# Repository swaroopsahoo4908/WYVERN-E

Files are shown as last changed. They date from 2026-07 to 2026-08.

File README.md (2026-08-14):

# GTR70E WYVERN

**Authors:** Swaroop Sahoo, Chris Liu, Allison Hong  
**Program:** GTR70E WYVERN

A single-stage, 70 mm, finned active-TVC sustainer built around a **Raspberry Pi Pico 2 W** on a
20 x 24 (50 x 70 mm) perfboard, mounted as an axial card in the avionics bay, powered by an
**Estes F15-4**.

The vehicle answers five research questions, run across computational simulation, ground-based
instrumented testing, and powered flight:

- **RQ1, actuator class.** Magnetic-solenoid vs. servo thrust-vector control, compared on two
  physically separate, instrumentally identical three-axis load balances. The vehicle flies servo.
- **RQ2, zoned materials.** ASA-Aero, PETG-CF, and PC-FR allocated by section (upper body, lower
  body/fins, TVC assembly), justified by bend-to-fracture and thermal data, plus a blast-shield
  materials screen on the static-fire stand.
- **RQ3, fin aerofoil selection.** Bench wind-tunnel measurement of candidate fin sections,
  cross-checked against a 2D vortex-panel CFD solver.
- **RQ4, wind-tunnel-vs-flight calibration.** Barrowman-predicted stability checked against both
  tunnel measurement and reconstructed flight telemetry.
- **RQ5, control-gain sensitivity.** Closed-loop PID gain sets compared across repeated flights on
  the single-controller avionics architecture.

## Vehicle summary

Single stage, one Pico 2 W as flight computer and real-time controller: dual-core RP2350, one core
dedicated to the 500 Hz TVC loop, no Linux, native hardware PWM. Telemetry is logged to microSD as
the data of record; the onboard CYW43439 radio is used for bench telemetry on the ground stand. The magnetic-vs-servo comparison
runs on the ground (two matched three-axis load balances) rather than in flight, since that gives a
repeatable, directly-measured thrust vector instead of a single noisy flight-to-flight data point.

**Materials.** ASA-Aero forms the upper body that houses avionics (nose, recovery bay tube, FC bay
tube) and the lower body tube (chute/TVC bay); PETG-CF forms the fins and the bulkhead joint; PC-FR
forms the TVC assembly proper (motor mount, gimbal). Zoning follows thermal exposure and structural
role, not a single blanket material.

## Key numbers (see `Simulations/we4_sim.py` → `plots4/`)

| | value |
|---|---|
| Liftoff / dry mass | **720 g / 660 g** (finned 87 mm, no ballast) |
| T/W | 2.04 avg / 3.58 peak |
| Overall length | **672 mm** (Upper BT 198.4 · bulkhead 4 · Lower BT 350 · nose 120) |
| CG / CP / margin | 45.0 cm / 53.3 cm / **+1.14 cal** |
| Gimbal pivot / control arm | 54.8 cm / 9.9 cm from nose |
| Pitch inertia Iyy | 0.0201 kg·m² |
| Pitch authority | 17.2 rad/s² at the ±8° limit |
| Burnout | 3.45 s · 70.1 m · 34.4 m/s |
| Apogee | ~409 ft / 124.6 m @ 6.72 s (RK4+Barrowman) |
| Recovery | F15-4 motor ejection; deploys t≈7.45 s (+0.71 s past apogee) @ ~7.1 m/s; 24″ chute → 4.8 m/s descent |
| TVC | gimbal stays within ±8°; control authority positive throughout the burn |
| FAA class | Class 1, no waiver (720 g < 1500 g, F-class motor) |
| Flight computer | Pico 2 W on a 20×24 (50×70 mm) perfboard, axial card in the Upper BT |
| Sensors | BNO085 ×2 (bay 0x4B, gimbal 0x4A) · BME688 0x76 · BMP388 0x77 · microSD on SPI1 |
| Power | 2S 450 mAh LiPo → PPTC → arming switch → 5 V 3 A switching UBEC |
| Launch window | Nov 7–8 2026 primary, Nov 14–15 contingency; data close-out Dec 1 |

## Repository structure

```
GTR70E WYVERN/
├── README.md ← this file
├── .gitignore
├── Documentation/ ← all engineering docs, BOM, and build readiness
│ ├── README.md ← documentation index
│ ├── WYVERN_E4_BUILD_READINESS.md ← GO/NO-GO reconciliation report
│ ├── WYVERN_E4_Mathematics.md ← mass/CG/inertia, T/W, trajectory, TVC, recovery
│ ├── WYVERN_E4_Stability_FinSizing.md
│ ├── WYVERN_E4_FEA_Structural.md
│ ├── WYVERN_E4_Recovery.md
│ ├── WYVERN_E4_Camera_Solution.md
│ ├── WYVERN_E4_GSE_TestStands.md
│ ├── WYVERN_E4_PID_AUTOTUNE_REPORT.md
│ ├── WYVERN_E4_BOM.xlsx ← master BOM + purchase links
│ ├── WYVERN_E4_Timeline_3Month.md ← build-to-flight schedule
│ ├── WYVERN_E4_Build_Guide.md ← print/bench/assembly/ground-test/range procedures
│ ├── CANONICAL_NUMBERS.md ← single source of truth for every vehicle number
│ ├── FLIGHT_READINESS.md
│ ├── COMPATIBILITY.md
│ └── CONFLICTS.md ← defect log and design-decision record
├── Flight Computer/ ← Pico 2 W spec, firmware, perfboard wiring, GSE test rigs
│ ├── README.md
│ ├── 01_FlightComputer_Spec.md ← architecture, pin map, power, separation
│ ├── firmware/wyvern4_tvc/ ← flight + ground-stand firmware (one image, role flag)
│ └── wiring/ ← perfboard wiring + bay layout diagrams
├── Simulations/ ← Python RK4 suite, OpenRocket, dataset generator
│ ├── we4_flight_reduce.py ← post-flight SD log → RQ3/RQ4 results (--selftest first)
│ ├── README.md
│ └── wyvern_datagen/ ← Monte Carlo atmospheric dataset generator + GUI
│ └── README.md
├── 3D parts/ ← airframe + gimbal STL/STEP
├── Motor Test Stand/ ← static thrust stand + 3-axis TVC balances
├── Wind Tunnel/ ← bench aerofoil rig
├── Senior Research/ ← standalone research proposal (MD / DOCX / PDF)
├── Data/ ← flight and motor data (populated during testing)
└── Paper/ ← final research paper
```

## Ground test program

Four purpose-built stands: a static-fire stand (thrust-curve calibration, engine-bay thermal
verification, and the RQ2 jetvane blast-shield screen), a servo TVC stand, a physically separate
magnetic TVC stand, and a bench wind tunnel for RQ3/RQ4 aerofoil work. See
`Documentation/WYVERN_E4_GSE_TestStands.md` for the full build-out and instrumentation. The ground
rigs' load-cell DAQ runs on separate off-the-shelf boards. The TVC balance, however, reuses the
*same* Pico 2 W avionics stack and the *same* firmware image as the flight vehicle, built with
`-DWYVERN_GROUND_TEST=1` so the bay IMU is not required and launch-detect and recovery compile
out — the gimbal IMU is the sensor the stand exists to measure.

Design and decision history, including why specific numbers or scope changed, lives in
`Documentation/CONFLICTS.md` rather than here.

## References

Raspberry Pi Ltd. (2024). *RP2350 datasheet*. https://datasheets.raspberrypi.com/rp2350/rp2350-datasheet.pdf

Estes Industries. (n.d.). *F15-4 engines* [Product specification]. Retrieved August 12, 2026, from https://estesrockets.com/products/f15-4-engines

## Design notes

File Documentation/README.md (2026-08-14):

# GTR70E WYVERN, Documentation

**Authors:** Swaroop Sahoo, Chris Liu, Allison Hong  
**Program:** GTR70E WYVERN

Five research questions, each addressed by at least two independent methods: RQ1 magnetic-vs-servo
TVC (two separate physical test stands), RQ2 zoned materials and jetvane blast-shield screen, RQ3
fin aerofoil selection (wind tunnel + CFD), RQ4 wind-tunnel-vs-flight stability calibration, RQ5 PID
gain sensitivity. `WYVERN_E4_Timeline_3Month.md` has the build-to-flight schedule, two launch
weekends around Thanksgiving, all data collected by Dec 1.

- `WYVERN_E4_Mathematics.md`, mass/CG/inertia, T/W, trajectory, TVC, recovery, no-waiver.
- `WYVERN_E4_Stability_FinSizing.md`, Barrowman fin sizing: flown 87 mm fins give +1.14 cal, no ballast.
- `WYVERN_E4_FEA_Structural.md`, first-order structural + thermal margins.
- `WYVERN_E4_Camera_Solution.md`, i3 4K Thumb Action Camera offload solution (OV2640 SPI can't do 720p30).
- `WYVERN_E4_Recovery.md`, F15-4 motor-ejection recovery via two-body-tube separation at the bulkhead joint (finned vehicle, custom PCB in the upper BT).
- `WYVERN_E4_GSE_TestStands.md`, the four ground-test rigs: static-fire stand (calibration, thrust curves, jetvane blast-shield screen), servo TVC stand, magnetic TVC stand, wind tunnel (RQ3/RQ4 aerofoil testing).
- `WYVERN_E4_Timeline_3Month.md`, build-to-flight schedule at 3 man-hrs/week (excludes print time, includes CAD/post-processing), two launch weekends bracketing Thanksgiving, all data by Dec 1.
- `WYVERN_E4_Timeline_14Day.md`, day-by-day procedure-level reference for what happens inside each build session.
- `WYVERN_E4_Build_Guide.md`, print / bench / assembly / ground-test / range procedures with go-no-go cards.
- `WYVERN_E4_BOM.xlsx`, master BOM with purchase links against the live Amazon/Adafruit/Estes/Bambu carts. The custom PCB fab line is retired; the flight computer is a Pico 2 W on a generic perfboard, and power is a discrete 5 V switching UBEC. Line-by-line notes live in the sheet itself.
- `WYVERN_E4_Cart_Gap_Analysis.md`, what the current cart is missing vs. the BOM and the design.
- Flight computer: `../Flight Computer/01_FlightComputer_Spec.md`, `firmware/`, `wiring/`, `flowcharts/`.
- Sims/plots: `../Simulations/we4_sim.py` + `we4_analysis.py` → `../Simulations/plots4/`.
- Datasets: `../Simulations/wyvern_datagen/` (Monte-Carlo + SIL generator, sharded ≤80 MB/file).

Design-decision history and defect records, why specific numbers changed and when, live in
`CONFLICTS.md`, not in this index.

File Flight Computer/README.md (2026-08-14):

# GTR70E WYVERN, Flight Computer

*Raspberry Pi Pico 2 W on a 20 x 24 perfboard, flight computer and real-time TVC controller.*

See `01_FlightComputer_Spec.md` for the full architecture writeup, and
`Documentation/CANONICAL_NUMBERS.md` for the vehicle numbers every doc should agree with.

---

## Architecture summary

Dual-core RP2350 split for determinism:

- *Core 0, real-time control.* 500 Hz TVC loop only: read both BNO085 units (Game Rotation
  Vector), vote attitude, run PID, command servos. Nothing on core 0 blocks.
- *Core 1, logging + comms.* Drains the inter-core ring buffer to microSD over SPI1, services
  WiFi telemetry (bench only -- the Pico 2 W does have a CYW43439 radio, but flight logs to card
  as the data of record), handles housekeeping.

Four sensors on one shared I2C bus, no mux:

| Device | Address | Strap |
|---|---|---|
| BNO085, bay | 0x4B | DI wired to 3V3 |
| BNO085, gimbal | 0x4A | DI unconnected |
| BME688 | 0x76 | SDO wired to GND |
| BMP388 | 0x77 | SDO unconnected |

Two body tubes, one bulkhead joint:

| Bay | Contents |
|---|---|
| Upper BT (FC bay) | Perfboard card: Pico 2 W, bay BNO085, BME688, BMP388, microSD breakout, LiPo, UBEC, arming switch, i3 4K Thumb camera |
| Bulkhead joint | Motor-ejection separation point; seven dupont leads part here |
| Lower BT | 24" chute, Nomex, aramid cord, then the TVC bay: F15-4, 2-axis gimbal, 2x ES08MA II, gimbal BNO085 |

The arming switch is reached by pulling the nose cone. The gimbal BNO085 IS gimbal-mounted on the
flight vehicle, so deflection is directly measurable in flight, not just on the ground rigs.

PID gains: *Kp* 0.10 / *Ki* 0.40 / *Kd* 0.18, +-8 deg gimbal authority, 500 Hz.

## Dual role

The same board and firmware image run the ground TVC/servo stand. Build with
`-DWYVERN_GROUND_TEST=1` and the bay IMU stops being required, launch detect and recovery compile
out, and WiFi telemetry turns on. See `firmware/wyvern4_tvc/wyvern_config.h`.

---

## Folder structure

```
Flight Computer/
├── README.md ← this file
├── 01_FlightComputer_Spec.md ← full architecture + sensor config
├── firmware/
│ └── wyvern4_tvc/
│ ├── wyvern4_tvc.ino ← main flight firmware (Arduino-Pico core, board "Raspberry Pi Pico 2 W")
│ ├── wyvern_config.h ← pin map, I2C addresses, flight/ground-stand role switch
│ ├── wyvern_pid.h ← PID controller
│ ├── imu_grv.h ← BNO085 Game Rotation Vector driver (both units)
│ ├── sd_logger.h ← microSD ring-buffer logger (SPI1)
│ ├── wifi_telemetry.h ← WiFi bench telemetry (ground stand only)
│ ├── baro.h ← BME688 + BMP388 barometric driver
│ ├── battery.h ← GP26 divider battery monitor
│ └── launch_status.h ← launch detect / flight state
├── flowcharts/ ← Mermaid state/logic diagrams
│ ├── 01_flight_state_machine.mermaid ← BOOT→ARMED→BOOST→COAST→RECOVER→LANDED
│ ├── 02_tvc_control_loop.mermaid ← 500 Hz PID loop flowchart
│ ├── 03_recovery_logic.mermaid ← motor-ejection separation logic
│ └── 04_power_tree.mermaid ← power distribution diagram
├── ground_test_rigs/ ← standalone bench DAQ sketches (load cells, HX711)
│ ├── wyvern4_gse_servo_rig/
│ └── wyvern4_gse_solenoid_rig/
├── test_code/
│ ├── t1_i2c_scan.ino ← I²C bus scan (expect 0x4A, 0x4B, 0x76, 0x77)
│ ├── t2_imu_grv_deflection.ino ← GRV deflection read + servo command check
│ ├── t3_servo_sweep.ino ← full ±8° gimbal sweep test
│ ├── t4_sensors_sdlog.ino ← all sensors → microSD log verification
│ ├── host_monitor.py ← WiFi telemetry monitor (run on laptop)
│ └── selftest.py ← automated bench self-test sequence
└── wiring/
    ├── wyvern_perfboard_wiring.svg ← hole-by-hole perfboard wiring + power chain
    ├── wyvern_bay_layout.svg ← bay layout + separation-joint cabling
    ├── gen_perfboard_diagram.py ← regenerates the wiring diagram
    └── gen_bay_layout.py ← regenerates the layout diagram
```

---

## Bench test sequence

Run these in order before any motor firing:

1. `test_code/t1_i2c_scan.ino`, confirm both BNO085s respond on their expected addresses.
2. `test_code/t2_imu_grv_deflection.ino`, manually tilt the airframe, verify body/external
   quaternions agree and servo commands track.
3. `test_code/t3_servo_sweep.ino`, full ±8° sweep, check for binding and correct direction.
4. `test_code/t4_sensors_sdlog.ino`, all sensors write to microSD; verify file on SD card.
5. `test_code/selftest.py` + `host_monitor.py` (laptop), USB-serial bench self-test verification.

Upload firmware via Arduino IDE 2.x with the [Arduino-Pico core](https://github.com/earlephilhower/arduino-pico) installed, board **"Raspberry Pi Pico 2 W"** (`rpipico2w`).

---

## Flight state machine

```
BOOT → ARMED → BOOST (F15-4 burn, 3.45 s, 500 Hz TVC) → COAST (brief)
     → RECOVER (motor ejection ~t=7.5 s, bulkhead joint separates) → DESCENT → LANDED
```

See `flowcharts/01_flight_state_machine.mermaid` for the full Mermaid diagram.

---

## Related

- `../Documentation/WYVERN_E4_BUILD_READINESS.md`, GO/NO-GO checklist
- `../Documentation/WYVERN_E4_PID_AUTOTUNE_REPORT.md`, PID gain derivation
- `../Simulations/we4_atmos_tvc.py`, closed-loop TVC atmospheric simulation

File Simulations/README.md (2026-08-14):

# GTR70E WYVERN, Simulations

- `we4_flightsim.py` → `plots4/01_trajectory.png` + `flightsim_summary.json`, **unified RK4(2e-4) + Barrowman engine** (apogee 397 ft @ 6.67 s, motor-ejection deploy at t=7.45 s / 7.7 m/s, finned margin +1.14 cal).
- `we4_sim.py` → `plots4/`, mass/CG/inertia, F15-4 trajectory, TVC pitch control + authority,
  recovery, dispersion (`01`–`06`) + `results_summary.json`.
- `we4_analysis.py` → `plots4/`, drag buildup (`07`), first-order structural/FEA margins (`08`),
  engine-bay thermal soak (`09`), power budget (`10`), apogee sensitivity tornado (`11`), gimbal/
  servo sizing (`12`).
- `build_ork4.py` → `WYVERN_E4_F15-4.ork` (open in OpenRocket 23.09 for an independent cross-check
  of the Barrowman CP/CG and trajectory; OpenRocket cannot model the active-TVC contribution, so the
  TVC results here are the authority).

Run: `python3 we4_flightsim.py && python3 we4_sim.py && python3 we4_analysis.py && python3 build_ork4.py`.

Key results: liftoff 729 g · T/W 2.01/3.54 · CG 45.0 cm / CP 53.3 cm (+1.14 cal) · Iyy 0.0257 kg·m² ·
apogee 397 ft @ 6.67 s · v_max 34.5 m/s (Mach 0.101) · rail exit pending re-verify against the
zoned-material mass stack · min SF ~340× · engine wall ~47 °C · gimbal torque ~0.56 kg·cm (±8°) ·
battery 450 mAh → ~40 flights/charge.

## Flight-validation suite (`we4_validation.py` → `plots_val/`)
Eight independent simulations with hard PASS/FAIL gates → `plots_val/validation_summary.json` +
`01_trajectory` `02_stability_margin` `03_rail_departure` `04_tvc_authority` `05_wind_weathercock`
`06_montecarlo` `07_landing_scatter` `08_recovery` `09_verdict`. Run `python3 we4_validation.py`.
Result: **10/13 gates pass**. The 3 flags share one root cause, the F15 is underpowered for the
729 g vehicle (rail-exit and weathercock margins per we4_stability.py). Mitigated by active
TVC (63.2x the required maneuver moment, airspeed-independent, engages t=0.5 s) + low-wind launch.

## Deep sim batch (`we4_deepsim.py` → `plots_deep/`)
Second-tier engineering checks for the F15-4 single-stage servo-TVC config (`deepsim_summary.json`):
A fin flutter/divergence (NACA TN-4197; PETG-CF fin margin 21.1× over v_max, PLA 13.8×, at Mach 0.087) · B aero heating (peak skin
≪ ASA/PETG-CF Tg, low-speed flight) · C servo torque (**2.3× margin** vs 0.20 N·m stall at the full ±8° limit, FLAGGED) · D CG-tolerance
(0.81 cal at 20 mm aft build error; 1.0 cal holds to 7 mm aft) · E rod-angle×wind dispersion grid · F TVC step response
(rise 0.36 s, ~0% overshoot, settle 0.46 s) · G drag ±25% (stays <1000 ft) · H battery endurance.
**Result: 7/8 pass.** The one flag is **C servo torque: 2.3x margin against stall, below the 3.0x
gate.** That number moved because the hinge moment is now evaluated at the FULL +-8 deg gimbal
limit rather than at a mid-range 5 deg, which had understated worst-case load by 1.6x. It is a
real finding, not a regression, and it is directly measurable on the TVC balance during the RQ1
ground campaign -- see `Documentation/WYVERN_E4_Timeline_14Day.md` Day 9.
Run `python3 we4_deepsim.py`.

## Motor decision
`we4_motor_tradestudy.py` is the record of the F15 motor-class choice: it is the only motor holding both the
<1000 ft ceiling (397 ft / 121.1 m) and the long 2.95 s TVC window (the three-way trade is documented).

## Atmospheric TVC + PID (`we4_atmos_tvc.py` → `plots_atmos/`, `pid_reference.py`)
Closed-loop pitch-plane TVC through 4 atmospheres (cold/ISA/hot/high-DA + humidity) with mid- and
late-burn gusts. Key results: dynamic pressure q (and thus gust forcing + fin damping) both scale
with density and partly cancel. Tuning revealed the old Kp=8 gains RING against the 40 ms servo
lag, and a follow-up margin analysis (`Documentation/PID_TUNING_REPORT.md`) that adds the 2 ms
control-loop delay on top of the servo lag showed the next-tried Kp=2.0/Ki=0.4/Kd=0.5 gains are
*also* unstable in the worst case (negative phase/gain margin, Cold −15°C early-burn). Final,
margin-validated gains: **Kp=0.10 / Ki=0.40 / Kd=0.18**, worst-case phase margin 44.7°, gain
margin 12.6 dB, gust pitch deviation 1.96° / gimbal 2.35° (limit ±8°) across all 4 atmospheres.
`pid_reference.py` is the Python twin of `firmware/wyvern_pid.h`. Gain-scheduling adds <1% ⇒ a
simple fixed-gain PID is used. Run `python3 we4_atmos_tvc.py`.

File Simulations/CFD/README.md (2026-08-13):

# CFD, Fin Airfoil Aerodynamics (RQ3/RQ4)

> Numbering below uses the project's five-RQ scheme: RQ3 is fin aerofoil selection, RQ4 is
> wind-tunnel-vs-flight calibration. RQ1 is magnetic-vs-servo TVC actuation (`WYVERN_E2_airfoil_polars.xlsx`'s
> filename is a legacy artifact and doesn't reflect the current numbering).

A 2D vortex-panel-method solver for the four candidate fin cross-sections, in pure
Python/numpy. Supports the wind-tunnel campaign (RQ3/RQ4) by predicting the lift curve
and surface pressure of each profile through the 0.5° deflection sweep, giving a
computational baseline to validate the tunnel measurements against.

## Files
- `airfoil_profiles.py`, geometry for NACA 0006, NACA 0012, double-wedge, flat-plate (unit chord, cosine-spaced, clockwise loops).
- `run_airfoil_cfd.py`, constant-strength vortex-panel method (Kuethe & Chow) → Cl and Cp; flat-plate skin-friction model for a viscous Cd estimate; AoA/deflection sweep in 0.5° steps at tunnel (Re 2e5) and flight (Re 3.4e5) Reynolds numbers.
- `airfoil_polars.csv`, Cl, Cd, L/D vs deflection for every profile.
- `cl_alpha.png`, `cp_distribution.png`, lift curves and Cp distributions.
- `WYVERN_E2_airfoil_polars.xlsx`, formatted workbook (Summary + Polars), formula-driven Cl-slope / Cl@5° / best-L/D.

## Run
```
python3 run_airfoil_cfd.py # prints a validation line, writes CSV + plots
```

## Validation & caveats
The method is validated against thin-airfoil theory: NACA0012 returns dCl/dα ≈ 0.120/deg
(≈110% of the 2π/rad ideal, the expected inviscid thickness over-prediction); the thin
flat-plate returns ≈0.112/deg. The solver is *inviscid*: it captures Cl and the pressure
distribution but not viscous separation, stall, or pressure drag. Real Cd and stall onset
come from the RQ3/RQ4 wind tunnel, which is exactly what this code is built to be checked
against. For full-vehicle 3D RANS, the program uses SimFlow/OpenFOAM separately.

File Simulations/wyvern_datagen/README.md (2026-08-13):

# GTR70E WYVERN, Simulation & Dataset Suite

Start from loaded:
cd ~/"Library/Mobile Documents/iCloud~md~obsidian/Documents/Skylight/Projects/Skylight/WYVERN/GTR70E WYVERN/Simulations/wyvern_datagen"
/opt/homebrew/bin/python3 run_gui.py

One Python GUI + engine that generates **millions of atmospheric datapoints** for the GTR70E WYVERN
rocket, and links the project's existing single-run simulation engines under the same window.

This replaces the old Java/OpenRocket `arc-sim` tool (which was wired to the CSW project, its
`CSWARCMOD*.ork` files have been removed). The physics here matches the project's canonical engine
`../we4_flightsim.py` (nominal apogee **98.9 m / 324 ft @ ~6.27 s**), so datasets are consistent
with the rest of the WYVERN sim suite.

## Quick start

Use **one** interpreter that has both a modern Tk (for the GUI) and the packages. On macOS that's
Homebrew's Python: `/opt/homebrew/bin/python3` (Apple Silicon) or `/usr/local/bin/python3` (Intel).

**One-time setup** (installs the toolkit + packages into that interpreter):

```bash
brew install python-tk # modern Tk 8.6 for the GUI
/opt/homebrew/bin/python3 -m pip install numpy pyarrow matplotlib # (add --break-system-packages if pip refuses)
```

**Open the GUI**, pick either:

```bash
# a) double-click launch.command in Finder (auto-picks a working Python), OR
# b) from a terminal:
cd ~/"Library/Mobile Documents/iCloud~md~obsidian/Documents/Skylight/Projects/WYVERN/GTR70E WYVERN/Simulations/wyvern_datagen"
/opt/homebrew/bin/python3 run_gui.py
```

If a dependency is missing, `run_gui.py` prints the exact install command for *that* interpreter
instead of a traceback. Sanity check anytime:

```bash
/opt/homebrew/bin/python3 -c "import numpy, pyarrow, matplotlib, tkinter; print('deps OK')"
```

**Headless / scriptable** (recommended for multi-million-row runs), run from this folder. Each run
writes a new `*_YYYYMMDD_HHMMSS` file; add `--no-timestamp` to overwrite a fixed name instead:

```bash
/opt/homebrew/bin/python3 datagen.py outcomes --n 2000000 --out datasets/outcomes.parquet
/opt/homebrew/bin/python3 datagen.py timeseries --flights 50000 --stride 10 --out datasets/ts.parquet
/opt/homebrew/bin/python3 datagen.py tvc --n 1000000 --out datasets/tvc.parquet
/opt/homebrew/bin/python3 datagen.py combined --flights 25000 --out datasets/combined.parquet # closed-loop SIL batch
```

## GUI at a glance

Opens maximized (fill screen); **F11** toggles true fullscreen, **Esc** exits it.

- **Atmospheric Datasets**, choose type, N flights, seed, format; one-click envelope **presets**
  (Calm / Typical field / High wind / Hot & high / Full envelope); Preview count + real ETA;
  progress bar, live log, working Cancel; "Quick nominal flight ▶" plots a single reference flight.
  Every run writes a **new timestamped file** (arc-sim style, never overwrites); untick "New file
  each run" to reuse a fixed name.
- **Plots & Analysis**, load any dataset (or "Load last generated") and build **histograms,
  scatter, density hexbin, altitude-trajectory overlays, and correlation heatmaps** in an embedded
  matplotlib canvas with the standard zoom/pan/**save-PNG** toolbar; per-column statistics panel.
  Large sets are auto-subsampled so plotting stays responsive.
- **Data Viewer**, a tabular **Parquet/CSV viewer** with a **dark grid** (white text on a dark
  background, white row/column outlines, rows drawn a touch thicker). Full column headers, numeric
  formatting + right-alignment, horizontal & vertical scrolling, **click-a-header-to-sort**, and a
  start-row / row-count window (**default 10,000 rows**). The grid is drawn on a virtualized canvas,
  so only on-screen rows render and it stays fast even on multi-million-row files. Also opens the
  last generated file.
- **PID Tuner**, live closed-loop TVC tuning: drag **Kp / Ki / Kd** (plus gimbal limit, wind,
  turbulence, and disturbance type) and watch the pitch θ(t) and gimbal δ(t) response redraw in
  real time, with tuning metrics (peak overshoot, settle time, steady-state error, RMS gimbal,
  saturation %) and the firmware-default gains overlaid for comparison. **Auto-tune** runs a robust
  multi-wind gain search (~10 s) and "Apply best" loads it; "Reset to firmware" restores Kp0.10/Ki0.40/Kd0.18.
- **Flight Computer SIL**, a software-in-the-loop *digital twin*: runs the FC's own processes
  (state machine BOOT→…→LANDED, 500 Hz PID on **noisy** simulated sensors, motor-ejection recovery)
  against a simulated flight with altitude-varying wind, and streams the **simulated Wi-Fi telemetry**
  (`HB:` heartbeat lines) to a live console while plotting altitude/pitch/gimbal. Shows true-vs-baro
  altitude, boost-phase control, and the apogee nose-over.
- **Super Combined**, batch-runs the full closed-loop SIL over **N random-condition flights**
  (default **25,000**), building a **live scatter** (wind vs boost-phase peak pitch, coloured by
  gimbal saturation) as flights complete, with progress + ETA + Cancel. Saves **two** timestamped
  files: the full time-series `*_log` and a compact per-flight `*_flights` summary. ~14 flights/s
  (25,000 ≈ 30 min); Cancel keeps whatever was written.
- **Static Motor Tester**, pick a motor (Estes C6/D12/E12/E16/F15) and see its thrust curve plus the
  **axial load-cell trace** the static stand would log (DAQ rate + sensor noise), with total impulse,
  avg/peak thrust, burn time, and a load-cell headroom/under-range check.
- **Jetvane Suitability**, **RETIRED 2026-08.** Jetvane TVC was dropped from the program; the
  tab still opens for reference but its output is not used by any research question and no jetvane
  hardware is built or fired. Kept only so the earlier trade study stays reproducible.

- **Ground TVC + PID**, the **3-axis thrust-vector balance** reading (Fz axial, Fx/Fy lateral) while
  the firmware PID gimbals the nozzle through a bench maneuver (step / sweep / PID disturbance-reject),
  including servo lag; shows commanded-vs-measured δ, the resolved vector, saturation, and cell headroom.
- **Project Engines**, run the existing `we4_*.py` engines; each run archives its plots to a fresh
  `plots*_<timestamp>/` folder (set via the `WYVERN_RUN_TAG` env var) so nothing is overwritten.
- **About**, canonical specs + the headless CLI reference.

## Dataset types

| Type | Rows | Columns | Use |
|---|---|---|---|
| `outcomes` | 1 per flight | sampled atmosphere → `apogee_m/ft`, `apogee_t`, `max_speed_ms`, `max_mach`, `max_q_pa`, `max_accel_g`, `burnout_*`, `deploy_*`, `descent_rate_ms`, `flight_time_s`, `landing_x_m`, `drift_from_pad_m` | dispersion / robustness statistics |
| `timeseries` | ~149 per flight (dt 5 ms, stride 10) | `flight_id, t, x, z, vx, vz, accel_g, mach, q` + per-row conditions | ML training / trajectory learning |
| `tvc` | 1 per flight | `peak_pitch_err_deg`, `rms_gimbal_deg`, `gimbal_saturation_pct`, `settle_time_s` + conditions | closed-loop TVC control performance |
| `flightlog` | SIL time-series | `state_id, alt, vz, pitch, gimbal, baro, batt` + conditions | closed-loop digital-twin logs (state machine + sensor noise) |
| `combined` | log + per-flight summary | full SIL log **plus** `apogee, peak_pitch_boost, rms_gimbal, gimbal_sat, deployed` per flight | the Super Combined batch (default 25,000 flights) |

Every flight samples an atmosphere/launch condition uniformly over a tunable envelope (wind speed &
bearing, turbulence, surface temperature, pressure, launch-rod tilt, field elevation). The GUI
exposes every envelope bound; the defaults cover a realistic small-field F-class envelope.

## Physics (vectorized)

`core.py` integrates **N flights in lock-step as NumPy arrays**, that vectorization is what makes
million-flight datasets tractable in pure Python. It reuses the canonical WYVERN model:

- F15-4 thrust curve (49.6 N·s / 3.45 s), linear propellant burn, `m_lift 792 g → m_dry 690 g`.
- Barrowman drag build-up (Cd ≈ 0.54), ISA atmosphere with sampled temperature/pressure perturbation.
- 2-D point mass with wind drift; analytic 24″-parachute descent (terminal ≈ 6 m/s) after the
  F15-4 ejection at t = 7.45 s.
- **TVC**: reduced-order closed-loop pitch plant (aerodynamic angle-of-attack spring + damping +
  the firmware PID `Kp0.10/Ki0.40/Kd0.18`, ±8° gimbal, 500 Hz, anti-windup), held straight on the
  1 m rail then released. Peak pitch error scales with wind (≈0° calm → ≈19° at 10 m/s), consistent
  with the documented low-speed weathercocking of this low-T/W vehicle.

Nominal check: `python3 core.py` → `98.9 m / 324 ft @ 6.27 s` (matches `we4_flightsim.py`).

## Throughput & scale

Measured on this dev machine (single core, NumPy):

| Dataset | Rate | 1 M rows | 10 M rows |
|---|---|---|---|
| outcomes (dt 5 ms) | ~8,600 flights/s | ~2 min | ~20 min |
| tvc (dt 2 ms, 500 Hz) | ~5,000 flights/s | ~3.5 min | ~35 min |
| timeseries (dt 5 ms) | ~90,000 rows/s | ~11 s | ~2 min |

Data is **streamed to disk in chunks**, so memory stays flat no matter how large the dataset. There
is no practical row cap, pick the row count you want and let it run.

## Output format

**Parquet** by default (compact, columnar, snappy-compressed, ideal for the huge time-series set and
loads directly into pandas/DuckDB/Polars). Falls back to **gzip-CSV** if `pyarrow` isn't installed.
Note: `.xlsx` is *not* used, it caps at ~1.05 M rows, well below "millions."

```python
import pyarrow.parquet as pq
df = pq.read_table("datasets/outcomes.parquet").to_pandas()
```

## Files

```
wyvern_datagen/
  core.py vectorized flight physics (outcomes / trace / TVC)
  datagen.py chunked Monte-Carlo writers + CLI
  analysis.py dataset loading + plot builders (histogram/scatter/hexbin/trajectory/corr)
  fc_sil.py flight-computer software-in-the-loop digital twin (state machine + sensors + telemetry)
  pid_autotune.py robust multi-wind PID gain search
  gui.py Tkinter GUI, 8 tabs: Atmospheric Datasets, Plots & Analysis, Data Viewer, PID Tuner, Flight Computer SIL, Super Combined, Project Engines, About
  run_gui.py GUI launcher (preflight dependency check)
  launch.command double-click launcher (Finder), auto-selects a working Python
  README.md this file
  datasets/ generated output (sample *_test.parquet included)
```

## Dependencies

`numpy` (required), `matplotlib` (GUI plots), `pyarrow` (optional, for Parquet), `tkinter` (GUI only,
ships with a Tk-enabled Python). No Java, no Maven, no OpenRocket.

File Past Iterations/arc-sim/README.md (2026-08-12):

# arc-sim: OpenRocket engines for ARC, with a desktop GUI

## Quick start: the GUI

Skip the CLI entirely if you'd rather click buttons than remember positional args:

```bash
cd ~/"Library/Mobile Documents/iCloud~md~obsidian/Documents/Skylight/Projects/CSW Aerospace/CSWARC'27/arc-sim"
mvn clean package
java -jar target/arc-sim-1.0.0.jar
```

That launches a desktop window with six engine tabs plus a seventh **Data Viewer** tab, file-picker
Browse buttons, a "Preview combination count & time estimate" button for the full sweep and batch
generator (so you see the number before committing to a multi-hour run), a live log, and a Cancel
button that actually stops a running job partway through -- including Engine 3's Design Solver,
which previously ignored Cancel entirely -- picking up at the next safe checkpoint and using/saving
whatever partial result it had accumulated so far, rather than just hanging until the run finishes
on its own.

**Engines 1, 2, and 3 each show a live leaderboard table** while running: the top 10 "most
favorable conditions seen so far" (Engine 1 / 2) or "closest simulation to target seen so far"
(Engine 3), re-ranked in place every time a new result beats an entry already on the table, so you
can watch the run converge instead of waiting for it to finish before seeing anything.

**Data Viewer tab**: a built-in, read-only browser for this toolkit's three tabular output
formats -- `.xlsx` (Engine 1, with a sheet selector), `.csv` (Engine 4's manifest), and `.parquet`
(Engine 2). Parquet reading/writing uses this project's own dependency-free `MiniParquet` (see
`MiniParquet.java`) rather than pulling in Apache Parquet's full Hadoop-based stack, so there's no
extra dependency weight for it. Point it at any file with Browse, click Open; there's a row cap
(default 20,000, adjustable) so opening a multi-million-row parquet file doesn't try to load it
all into the table at once.

**Every engine names its own output file/folder automatically** -- `<rocketName>_<simType>_<timestamp>`
-- so you never have to type a filename, and re-running an engine (even on the same rocket, even
in the same second) never overwrites a previous result; the output fields in the GUI now just
pick a destination *folder* (optional -- overrides the default below).

**Default output folders** -- leave the GUI's "Output folder" field blank and each engine writes
into its own fixed-name folder, created as a SIBLING of whichever `.ork` file you're running
against (not a fixed project-root location), so outputs stay organized next to the design they
came from no matter where that file lives:

| Engine | Default folder |
|---|---|
| Engine 1 (Monte Carlo sweep) | `Monte Carlo` |
| Engine 2 (full factorial sweep) | `Full Factorial` |
| Engine 3 (design solver) | `OpenRocket Solves` |
| Engine 4 (batch `.ork` generator) | `OpenRocket Solves` (each batch gets its own timestamped subfolder inside it) |
| Engine 5 (geometry export) | `CAD Files` |
| Engine 6 (weather-driven design) | `Engine 6` |

Typing an explicit path into the "Output folder" field bypasses the default entirely.

The CLI still works the same way -- positional args, no filenames to make up:

```bash
java -cp target/arc-sim-1.0.0.jar com.arc.sim.Main sweep CSWARCMOD1D.ork MDRA_SOD_FARM 5000
```

(Output paths in the CLI are all now optional trailing `[outputDir]` args -- omit them to write
next to the input `.ork`, same as the GUI.)

(`java -jar ...` launches the GUI; `java -cp ... com.arc.sim.Main ...` uses the CLI. Both read the
same code, just different entry points.)

Everything below describes what each engine does; the GUI's fields map 1:1 to the CLI args
described here.

---

Three independent engines:

1. **Engine 1 — `EnvironmentSweep`**: holds your rocket design EXACTLY as uploaded (no changes)
   and Monte Carlo samples across the full wind/turbulence/temp/pressure envelope, writing every
   run + a summary/sensitivity sheet to `.xlsx`.
2. **Engine 3 — `DesignSolver`**: holds ONE atmosphere/wind condition fixed (you specify it) plus
   your target apogee and flight-time window, and solves for **ballast mass + fin height + fin
   sweep** to hit those targets.
3. **Engine 4 — `OrkBatchGenerator`**: takes ONE base `.ork` and a grid of ballast / fin height /
   fin sweep / parachute center-hole values, and writes out **every combination as its own `.ork`
   file** — all landing together in one auto-named subfolder next to the base file, alongside a
   **`manifest.csv`** linking every generated filename to its parameter values. Optionally (via
   the grid config's `simCheck.*` properties) it will ALSO simulate each variant under one fixed
   atmosphere and check it against a target apogee/flight-time window — the same target+atmosphere
   shape Engine 3 takes — so each saved `.ork` carries real simulated flight data and the manifest
   records apogee/flight-time/meets-target per variant.

Engine 2's full-factorial output is `.parquet` (not `.xlsx`) since it routinely produces far more
rows than a spreadsheet can hold; Engine 4's manifest is `.csv`. All three tabular formats open in
this toolkit's own **Data Viewer** GUI tab.

The full factorial grid originally described (every combination of all 7 environmental variables
at fine increments) is ~1.33 trillion points — not runnable on any machine. Engine 1 covers the
same envelope with a statistically meaningful random sample instead.

## Your current file (CSWARCMOD1D.ork), as of this version

- Mass component is now explicitly named **"Ballast"**, 128 g, in the aft body tube — matches
  what you described (100+ g in the lowest section).
- Parachute is the **"Parachute, 18 in., nylon, 6 lines, PN 002261"**, 0.4572 m diameter — Engine
  3 holds this fixed and does not resize it.
- The saved Simulation 1 in the file already shows **apogee 242.98 m, flight time 41.586 s** —
  apogee is basically dead-on your 243 m target already; flight time is running long by
  1.6–4.6 s against your 37–40 s window. That gap is exactly what Engine 3 is for.
- Component lookup is still **structural** (lowest body tube = ballast, first fin set = fins,
  first parachute = recovery), not purely by name, so this keeps working if you rename things
  again later. See `RocketComponents.java`.

## 1. Prerequisites

- Java 17+, Maven
- Your `.ork` file (bundled in this zip)

## 2. Build

```bash
cd arc-sim
mvn clean package
```

Produces `target/arc-sim-1.0.0.jar`.

## 3. *** Verify units before trusting any output ***

`SimRunner.java` converts wind direction to radians, temperature to Kelvin, and pressure to
Pascals before handing them to OpenRocket's `SimulationOptions`. This matches the documented
`info.openrocket.core` API, but core APIs drift between versions. Before trusting real numbers:

1. Run one simulation through this tool with a known condition.
2. Set the same condition manually in the OpenRocket GUI's Simulation Options dialog.
3. Confirm apogee/flight time match within numerical noise (<1%).

## 4. Engine 1 — environment sweep

```bash
java -jar target/arc-sim-1.0.0.jar sweep CSWARCMOD1D.ork MDRA_SOD_FARM 5000
```

Args: `.ork` file (used as-is, unmodified), site, number of Monte Carlo samples, optional output
folder (defaults to a `Monte Carlo` folder next to the `.ork` file). The filename itself is generated automatically
as `CSWARCMOD1D_montecarlo_<timestamp>.xlsx` — every run gets its own file, so nothing is ever
overwritten even if you kick off two runs back to back.
Output `.xlsx` has:
- **Runs** sheet: every sampled condition + apogee/flight-time result
- **Summary** sheet: success rate (% of samples in your 243 m / 37.5-39.5 s window) and Pearson
  correlation of each environmental variable against apogee and flight time

Distributions are uniform across your full stated ranges (0-20 m/s wind, -5-35°C, 980-1020 mbar,
etc.) — swap in a fitted Gaussian/Rayleigh if you have real historical weather data for your
launch date, which will usually give a more realistic (and likely higher) success rate than this
worst-case uniform assumption.

## 4b. Engine 2 — TRUE full-factorial sweep (every combination, no sampling)

```bash
java -jar target/arc-sim-1.0.0.jar fullsweep CSWARCMOD1D.ork sweep_grid.properties
```

Same auto-naming as Engine 1 — output filename is generated as
`CSWARCMOD1D_fullfactorial_<timestamp>.parquet`, written to an optional trailing `[outputDir]` arg
(default: a `Full Factorial` folder next to the `.ork` file). A companion `..._summary.csv` (success rate +
correlations, the old xlsx "Summary" sheet) is written right alongside it.

This runs **every single combination** in the grid defined by `sweep_grid.properties` — no
sampling, nothing skipped. Your originally-requested increments (0.5 m/s wind, 0.1 m/s std dev,
1% turbulence, 0.5 deg direction, 1 deg C, 1 mbar pressure) produce **~388 billion**
combinations — ~369 years on one CPU core, ~23 years even on 16 cores. Not runnable at any
increment that fine, corrected pressure range or not.

`sweep_grid.properties` (bundled, edit freely) defaults to coarser increments that total ~1.63
million combinations — the tool prints the exact count and a rough time estimate **before it
starts**, so check that output before committing to a multi-hour run. If the total exceeds the
`maxCombosSafety` cap in the properties file (default 5,000,000), it refuses to run and tells you
so, rather than silently kicking off a job that'll finish next decade — pass `--force` to
override, or just coarsen the increments.

It's multithreaded (`threads=` in the properties file, defaults to your CPU's core count) — each
thread loads its own copy of the `.ork` so there's no shared-state risk between them. Output is
**Parquet, not xlsx**: a true full-factorial run routinely produces tens of millions of rows,
past Excel's ~1,048,576-rows-per-sheet ceiling the old xlsx writer had to chunk around. Every row
(one per combination) lands in a single `.parquet` file, written via this project's own
dependency-free `MiniParquet` writer (no Hadoop/parquet-mr dependency needed — see
`MiniParquet.java`), streamed in bounded row groups so memory stays flat no matter how many
combinations run. Open it in the GUI's **Data Viewer** tab, or in pandas/DuckDB/any other
Parquet-aware tool. The success-rate + correlation summary is the companion `_summary.csv`.

**Tuning tip:** time a small run first (e.g. set every `.step` larger to get ~10,000 combos,
confirm it finishes in a minute or two) to calibrate the real per-simulation time on your machine
before dialing in a bigger grid for your actual time budget.

## 5. Engine 3 — solve ballast + fin height + fin sweep

```bash
java -jar target/arc-sim-1.0.0.jar design CSWARCMOD1D.ork 243.0 37.5 39.5 MDRA_SOD_FARM \
    3.8 0.6 13.4 270 7.06 999.76
```

Args, in order: `.ork` file, target apogee (m), target flight-time min/max (s), site, wind avg
(m/s), wind std dev (m/s), turbulence intensity (%), wind direction (deg), temperature (°C),
pressure (mbar). The example values above match the atmosphere from your original Simulation 2
(3.8 m/s wind, 13.4% turbulence, ~7°C, ~1000 mbar).

**How it splits the 3 unknowns across 2 targets** (see full explanation in `DesignSolver.java`):
- **Ballast mass** is the primary lever for **total flight time** — heavier rocket descends
  faster under the same fixed parachute.
- **Fin height** is the primary lever for **apogee** — bigger fins add drag during ascent,
  lowering apogee. Its effect on total flight time is small since descent time is dominated by
  the parachute.
- **Fin sweep** is a weak last-resort trim, only touched if apogee still has residual error after
  ballast/fin-height converge. Sweep mostly affects **stability margin** (CP location), not
  apogee/time — after this solver runs, open the saved file in the OpenRocket GUI and check the
  stability margin (calibers) is still in a safe range (typically 1-2 cal) before you commit to
  flying with a changed sweep.

Output: prints the solved ballast/fin height/fin sweep and saves
`<orkName>_solved_<timestamp>.ork` into an `OpenRocket Solves` folder next to your input file (GUI:
override via the "Output folder" field) — never overwrites a previous solve, so
you can re-run with different targets/bounds and keep every attempt. If it can't converge both
targets, the tool tells you which bound (max ballast, max fin height) it hit — at that point your
options are a different motor (you already have F15, F25W, F26FJ, F20W/L, and a second F15 delay
variant configured) or accepting a compromise on one target.

## 5b. Engine 4 — batch `.ork` design-variant generator

```bash
java -jar target/arc-sim-1.0.0.jar batch CSWARCMOD1D.ork batch_grid.properties
```

Takes ONE base `.ork` and writes out **every combination** of the design-parameter grid in
`batch_grid.properties` as its own standalone `.ork` file. The same four physical knobs Engine 3
solves for are available to sweep: ballast mass (kg), fin height (m), fin sweep (m), and
parachute center spill-hole radius (inches). Leave an axis's `.min`/`.max`/`.step` trio out of the
config entirely to leave that parameter untouched (exactly as loaded from the base file) in every
generated file — so you can sweep just ballast, or all four at once. The bundled config sweeps
ballast + fin height + hole radius (a small ±1 in tolerance band) by default, leaving fin sweep
untouched, matching the current design-of-experiments plan.

All generated files land together in one new timestamped subfolder created inside an
`OpenRocket Solves` folder next to the base `.ork` (or inside an optional trailing
`[outputParentDir]` arg, which overrides that default): `CSWARCMOD1D_batch_<timestamp>/`. Each file inside
is individually named with its varied parameter value(s) baked in, e.g.
`CSWARCMOD1D_ballast150g_finH80mm.ork`, so the batch is self-describing and nothing — inside this
batch, a previous batch, or any other engine's output — can ever collide or get overwritten.

**`manifest.csv`** also lands in that subfolder, with one row per generated file linking its exact
filename (`ork_filename` column) to the parameter value(s) that produced it — open it in the GUI's
Data Viewer tab, or any spreadsheet, to browse or filter the whole batch without opening 100s of
individual `.ork` files.

**Optional: simulate + check against a target, same idea as Engine 1 but per design variant.**
By default no simulation runs here — pure design-variant generation. Fill in the grid config's
`simCheck.*` properties (all 10, or none — see the commented-out block in `batch_grid.properties`)
to also simulate every variant under one fixed atmosphere and check it against a target
apogee/flight-time window, the same target+atmosphere shape Engine 3 takes. When enabled:
- Each saved `.ork`'s own Simulation 1 gets the real simulated flight data cached into it — open
  it in the OpenRocket GUI and the apogee/flight-time are already there, rather than a design
  nobody's actually checked yet.
- `manifest.csv` gains `apogee_m`, `flight_time_s`, `meets_apogee`, `meets_time`, and `meets_both`
  columns, so sorting/filtering the manifest tells you which design variants actually hit the
  target without opening anything else.

Like Engine 2, it prints the total file count up front and refuses to run past a
`maxFilesSafety` cap (default 5,000) unless you pass `--force` — a typo in the grid step can't
silently ask for a million files.

Useful for: handing a batch of concrete design candidates to teammates, loading a handful
side-by-side in the OpenRocket GUI to eyeball, checking (via `simCheck.*`) which design variants
meet your target before you even open OpenRocket, or feeding each variant into Engine 1/2
separately for a fuller design-space sweep than Engine 3's single-atmosphere solve.

## 5c. Engine 5 — geometry export (`.ork` -> STL/OBJ)

GUI-only (no CLI command). Load any `.ork` in the "Engine 5: Geometry Export" tab, pick STL and/or
OBJ, and export a triangle mesh built from `RocketGeometryExtractor`'s nose-cone/body-tube/
transition radii-by-station plus each trapezoidal fin set's planform (root chord/tip chord/sweep/
height/fin count/base rotation). Written by this project's own dependency-free `MeshExporter` —
no CAD/mesh library dependency needed.

**This is a basic outer-mold-line converter, not CAD-fidelity geometry**: body sections are a
solid-of-revolution surface only (no wall thickness, no internal components, no fillets); fins are
flat extruded trapezoidal panels (a few mm of constant thickness, purely to make them a closed
solid) rather than real airfoil sections; multi-body stacking assumes serial nose-to-tail stacking
with no gaps (same assumption `RocketPreviewPanel` uses), so side-by-side staging (boosters/pods)
isn't rendered. Good for a quick 3D-print or CAD-import sanity check of the outer shape; not a
substitute for real CAD if you need dimensional precision. Output units are **millimeters**
(the de facto STL/CAD convention). Every run gets its own new `<rocketName>_geometry_<timestamp>/`
subfolder (same pattern Engine 4's batch generator uses) inside a `CAD Files` folder next to the
`.ork` file by default (override via the "Output folder" field) — so re-exporting the same rocket
never overwrites a previous run and both files from one export stay grouped together.

## 5d. Engine 6 — weather-driven design (live weather → Engine 3 → CAD → local sweep → margin fins)

GUI-only (no CLI command). Pulls real current conditions from weatherapi.com for whatever launch
site you pick, then chains together in one click: Engine 3's solve against that pulled atmosphere,
a full CAD export of the solved design, a Monte Carlo check of that solved design across a
realistic day-of range of conditions, and four spare fin-only CAD files sized for likely wind-speed
variance around the forecast. All of it -- the solved `.ork`, both CAD exports, the local sweep
`.xlsx`, and all four margin fin CAD pairs -- lands in one `Engine 6` folder next to the `.ork`
file by default; override via the "Output folder" field.

**Weather pull**: fetched once when the tab is built and at most once an hour after that — there's
no way to bypass the cooldown, so this can never hammer the API regardless of how many times you
click Fetch or Run. Wind speed/gust, direction, temperature, and pressure come straight from the
API; wind std dev does NOT (the API only reports a gust, not a variance) and is estimated as
`(gust - avg) / 2.5` — a rough turbulence rule of thumb, pre-filled into an editable field so you
can override it with better local knowledge. Turbulence intensity isn't reported at all and
defaults to 10%, also editable.

**Step 1 — main solve**: identical to running Engine 3 by hand with the pulled wind
average/direction, temperature, and pressure (plus the estimated/overridden std dev and
turbulence) as the fixed atmosphere. Saves `<rocketName>_solved_<timestamp>.ork` exactly like
Engine 3 does, with a live "closest simulation to target" leaderboard.

**Step 2 — main CAD**: exports the solved design as `<rocketName>_weatherdesign_<timestamp>.stl`
/ `.obj`, same converter as Engine 5.

**Step 3 — local-conditions sweep**: runs the SAME solved design (ballast/fin height/hole radius
unchanged) across a narrow envelope centered on the pulled reading — wind speed within ±2 std
devs, direction ±20°, temperature ±3°C, pressure ±5 mbar — answering "how much does ordinary
day-of variability move my already-chosen design's result," as opposed to Engine 1's wide
worst-case envelope. Writes `<rocketName>_localweather_<timestamp>.xlsx` (same Runs+Summary shape
as Engine 1) with its own live "most favorable local conditions" leaderboard.

**Step 4 — margin fin sets**: re-solves fin height ONLY (ballast and hole radius stay exactly as
solved in step 1) at four wind speeds — the pulled average ± 0.5 and ± 1.0 standard deviations —
and exports each as a standalone fin-set-only STL/OBJ (e.g. `..._finset_wind4_50ms_....stl`).
Example: a 5 m/s average with a 0.5 m/s std dev produces spare fin sets solved for 4.5, 4.75, 5.25,
and 5.5 m/s, so a team has a physical fin set ready to swap in if launch-day wind lands on one of
those margins instead of dead-center on the forecast.

Everything is written by this project's own dependency-free `MiniJson` (a small hand-rolled JSON
parser, matching `MiniParquet`'s existing dependency-free convention) and `WeatherClient` (built on
the JDK's own `java.net.http.HttpClient` — no HTTP library dependency needed).

## 6. Recovery speed heads-up (still relevant)

Your file's saved Simulation 1 shows a ~19.7 m/s deployment velocity — still on the fast side for
a chute opening (comfortable is usually under ~10-15 m/s), worth a look independent of anything
this tool outputs, since it's a recovery-hardware risk (shock cord snap, chute damage).

## 7. Launch site data

Coordinates live in `LaunchSite.java`. MDRA Central Sod Farm's lat/long come from MDRA's own
published field GPS marker; elevation is an unverified estimate. SPAAR Lancaster is geocoded from
a public address and not verified — confirm both against a GPS reading before relying on them.

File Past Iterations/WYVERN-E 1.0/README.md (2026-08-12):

# WYVERN-E 1.0

An experimental 70/127 mm research rocket demonstrating jet-vane thrust-vector control and a
custom avionics stack, serving as the first hardware PDR for the XRIM-117 WYVERN concept.

A Skylight Rocketry venture. Architecture revision PDR-004. *Superseded by WYVERN-E 2.0
(open-source solenoid TVC + custom RP2350B two-board PCB).*

---

## Overview

WYVERN-E 1.0 established the physical design envelope — two body diameter candidates (70 mm PDR-002
and 127 mm PDR-003/004), a jet-vane TVC geometry, the wind tunnel test infrastructure, and the
first KiCad avionics layout (XRIM117 RevB/C and XRIM117E). The program reached PDR-004 full
assembly before being superseded by the cleaner open-source two-board architecture of 2.0.

---

## Folder structure

```
WYVERN-E 1.0/
├── README.md                          ← this file
├── CAD:Models:PCB/                    ← OpenRocket sims, STL parts, KiCad PCBs, SVG schematics
│   ├── XRIM117_PTD_PDR002_70mm.ork    ← 70 mm PDR-002 baseline sim
│   ├── XRIM117E_PDR003_127mm.ork      ← 127 mm PDR-003 sim
│   ├── XRIM117E_PDR003_127mm_F15.ork  ← 127 mm F15-motor variant
│   ├── XRIM117E_PDR003_127mm_FLIGHT.ork
│   ├── XRIM117E_PDR004_FULL.ork       ← PDR-004 full assembly sim
│   ├── XRIM117E_PDR004_TVC_ONLY.ork   ← PDR-004 TVC-only stage sim
│   ├── XRIM117_all_parts/             ← 19-part STL library (nose, tubes, fins, gimbal, motor mount…)
│   ├── XRIM117E_KiCAD_RevC/           ← XRIM117E avionics KiCad RevC
│   ├── XRIM117_KiCAD_RevB/            ← XRIM117 avionics KiCad RevB
│   ├── XRIM117_EasyEDA_v3/            ← EasyEDA schematic source (pre-KiCad migration)
│   ├── xrim117_avionics_v4.svg        ← avionics schematic (SVG)
│   ├── xrim117_jetavane_tvc.svg       ← jet-vane TVC diagram (SVG)
│   ├── XRIM117_PCB_Layouts.html       ← rendered PCB layout view
│   ├── WYVERN_Engineering_Analysis.pdf ← structural and aero analysis
│   └── WYVERN_Simulator.md            ← flight simulation environment notes
├── Wind Tunnel/                       ← wind tunnel design, BOM, and test data
│   ├── Wind Tunnel Build.md           ← construction and instrumentation notes
│   ├── wind_tunnel_bom.xlsx           ← wind tunnel bill of materials
│   ├── WYVERN_wind_tunnel_spec.html   ← tunnel specification (HTML)
│   ├── WindTunnel_all_parts/          ← 14-part STL assembly (bellmouth, settling chamber,
│   │                                     contraction cone ×6, test section ×3, diffuser, fan)
│   └── WYVERN_WindTunnel_v2.zip       ← full tunnel archive
├── Docs:Decks/                        ← presentations and technical overview documents
│   ├── XRIM117_WYVERN_PitchDeck.pptx ← investor/competition pitch deck
│   ├── XRIM117_WYVERN_TechOverview.docx ← technical overview document
│   ├── XRIM117_PTD_PDR002_RevA_70mm.docx ← PDR-002 preliminary design review
│   └── XRIM117_NDA.docx               ← NDA (superseded by WYVERN/WYVERN NDA.md)
└── _OLD FILES/                        ← superseded PCB revisions (kept for reference)
    └── PCB/FCM_KiCAD/                 ← earlier KiCad layout with gerbers
```

---

## Key design parameters (PDR-004)

| Parameter | Value |
|---|---|
| Body diameters evaluated | 70 mm (PDR-002), 127 mm (PDR-003/004) |
| TVC method | Jet-vane (carbon-composite vanes in motor exhaust) |
| Avionics | Custom KiCad PCB — XRIM117 RevB → XRIM117E RevC |
| Wind tunnel | Open-return, 14-part 3D-printed, bellmouth inlet |
| Simulation | OpenRocket + custom Python flight simulator |

---

## Related

- `../WYVERN-E 2.0/` — successor: open-source solenoid TVC + RP2350B two-board PCB
- `../WYVERN/` — XRIM-117 concept and doctrine documents
- [[WYVERN MOC]] — Obsidian index

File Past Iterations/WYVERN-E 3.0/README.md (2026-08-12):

# WYVERN-E 3.0

An open-source, two-stage, 84 mm, 3D-printed research rocket demonstrating closed-loop
*thrust-vector control (TVC)* on an **off-the-shelf Raspberry Pi 5 flight computer**, flying a
direct **A/B comparison of two TVC actuation methods** (tri-solenoid vs servo-gimbal), with a
full ground-support ecosystem (wind tunnel + motor test stand).

A Skylight Rocketry venture by Allison Hong, Chris Liu, and Swaroop K. Sahoo. Architecture
revision PDR-006. *Supersedes 2.0 (custom RP2350B two-board PCB stack).*

## Overview

3.0 replaces the custom PCBs with a **Raspberry Pi 5** + COTS sensor harness: 3× BNO085
(gimbal/FC/nose), LSM6DSO32, LIS2MDL, BMP280, BME688, Camera Module 3, and dual 32 GB microSD
(no radio — data retrieved post-flight). The sustainer carries oversized fixed fins and a ±5°
TVC gimbal driven by **either** a tri-solenoid system **or** a servo system (BPS-style, up-rated
~8× for the G-motor thrust) — flown head-to-head. A long-burn **AeroTech G25W (4.7 s)** sustainer
gives the TVC demonstration window; an F-class booster clears the rod. The whole vehicle stays
**under the FAA/NAR no-waiver limits** (≤ 1500 g, ≤ 125 g propellant, ≤ G class).

## Research questions

1. Fin aerofoil profile and deflection aerodynamics (wind tunnel, 0.5° sweeps).
2. Print material and surface coating performance for fins (PC-FR, PETG-CF, ASA, PLA + coatings).
3. Motor thrust characterization and material erosion as jetvane candidates (test stand).
4. **TVC actuation A/B** — tri-solenoid vs servo-gimbal closed-loop control authority over a
   long sustainer burn (3 flights each).

## Repository structure

| Folder | Contents |
|---|---|
| `Senior Research/Proposal/` | Research proposal (Markdown / DOCX / PDF) |
| `Documentation/` | Technical document, mathematics, power/mass/motor analysis, TVC comparison, BOM, build/launch |
| `PCB/` | Off-the-shelf **flight-computer integration spec** + wiring diagrams (`.sch`) for the two TVC harnesses (no custom boards) |
| `3D parts/` | Rocket STL/STEP parts + parametric CAD generator (`_generator/`) |
| `Wind Tunnel/` | Fin-test mount + fan collar |
| `Motor Test Stand/` | Load-cell thrust-stand parts (20 kg cell for G-motors) |
| `Simulations/` | RK4 trajectory simulator, `we3_analysis.py`, plots (`plots3/`) |
| `Data/` | Flight, tunnel, motor, erosion data (populated during testing) |
| `Paper/` | Final research paper |

> The 3.0 flight computer is fully off-the-shelf. The legacy custom-board files inside `PCB/`
> (`FCM_KiCAD/`, `generator/`, `WYVERN_E2_*`) are superseded — delete them on your Mac (see
> `PCB/README.md`); the sandbox can't delete on the iCloud volume.

## Key specs

84 mm OD all-PC-FR · liftoff ≈ 1.29–1.39 kg · F booster + **G25W-10A** sustainer (RMS-29/120
casing) · apogee ~1015 ft · 3S 3000 mAh USB-C · Pi 5 + 3× BNO085 + LSM6DSO32 + LIS2MDL + BMP280
+ BME688 + Camera Module 3 + dual 32 GB µSD · RRC3+ recovery + 2nd-stage ignition · no waiver,
no L1 cert. Full numbers in `Documentation/WYVERN_E3_*`.

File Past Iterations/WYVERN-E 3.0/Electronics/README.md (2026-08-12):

# Electronics — WYVERN-E 3.0 (off-the-shelf)

**No custom PCBs.** The flight computer is a **Raspberry Pi 5** carrier with COTS breakout
sensors on an I²C/SPI harness. See `Documentation/WYVERN_E3_*` for architecture, the
power/mass/motor analysis, and the BOM.

## Contents

- `wiring/WYVERN_E3_solenoid_harness.kicad_sch` — tri-solenoid TVC driver wiring
- `wiring/WYVERN_E3_servo_harness.kicad_sch` — servo-gimbal TVC wiring

Both share the Pi 5 + sensor + power + RRC3+ core; only the TVC actuator branch differs.

## ⚠ Delete the old `PCB/` folder

The `PCB/` folder is the **superseded 2.0 custom two-board design** (carried over by the copy).
3.0 uses no custom PCBs, so `PCB/` should be deleted. The sandbox can't delete on the
iCloud-synced volume, so remove it manually:

```
rm -rf "WYVERN-E 3.0/PCB"
```

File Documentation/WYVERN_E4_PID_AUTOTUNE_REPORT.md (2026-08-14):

# GTR70E WYVERN, PID Auto-Tune & First-Flight Gain Confirmation

**Authors:** Swaroop Sahoo, Chris Liu, Allison Hong  
**Program:** GTR70E WYVERN

##### Time-domain robustness confirmation of the TVC pitch gains, complementing the frequency-domain margin analysis

## 1. Result (headline)

**The flight gains are confirmed unchanged for first flight: `Kp = 0.10, Ki = 0.40, Kd = 0.18`.**
A robust multi-wind auto-tune search (143 gain sets) finds the firmware gains within **~4 %** of the
grid-optimal time-domain cost, and shows that the small remaining gap is *not a tuning problem*, it
is the physical ±5° gimbal-authority limit of this low-T/W vehicle at high wind, which no gain set
can overcome. The gains are therefore validated by **two independent methods**: the frequency-domain
phase/gain-margin analysis (`PID_TUNING_REPORT.md`, PM ≈ 33°, GM ≈ 12.6 dB across 24 operating points)
and the time-domain robust auto-tune here.

## 2. Method

`Simulations/wyvern_datagen/pid_autotune.py` scores each gain set with a robustness cost averaged
over wind speeds {3, 6, 9, 12} m/s (15 % turbulence), using the same closed-loop pitch plant as the
flight TVC model (`core.simulate_tvc_trace`):

```
cost = mean_over_winds( peak_pitch° + 2·steady_err° + 0.3·settle_s + 0.5·RMS_gimbal° + 0.05·saturation% )
```

A coarse grid (Kp∈{0.05…0.5}, Ki∈{0…1.0}, Kd∈{0…0.5}) is refined around its best point.

## 3. Ranked results (top sets vs. firmware)

| Kp | Ki | Kd | cost | note |
|---|---|---|---|---|
| 0.15 | **0.00** | 0.28 | 46.36 | grid best, *drops integral* (see §4) |
| 0.20 | 0.00 | 0.12 | 46.40 | no integral |
| 0.15 | 0.00 | 0.20 | 46.50 | no integral |
| **0.10** | **0.40** | **0.18** | **48.44** | **firmware (flown)**, within 4.3 % of best |
| 0.15 | 0.25 | 0.25 | 48.14 | keep-integral nudge |
| 0.10 | 0.40 | 0.28 | 48.18 | more damping |

## 4. Why we keep integral action (and the firmware gains)

The grid's lowest-cost sets all set **Ki = 0**. That is an artifact of the cost function, not a good
flight choice:

- At the higher winds that dominate the averaged cost (9–12 m/s), the steady-state pitch error is
  **~17° for *every* gain set, including the firmware set**, because the ±5° gimbal is
  **authority-saturated** (a 720 g, ~2.1 T/W vehicle simply cannot vector enough thrust to hold
  attitude against that much crosswind). When the gimbal is saturated, integral action cannot move
  it further, so dropping Ki shaves a sliver of "wasted" gimbal effort and wins by ~4 %, a number
  well inside model noise.
- At the **low winds where the gimbal is *not* saturated**, integral action is exactly what nulls a
  *constant* pitch bias, thrust-axis misalignment, CG offset, a fin-can twist, a steady breeze.
  Those biases are real on a first flight and are **not** in this model. A PD-only (Ki = 0)
  controller would fly with a persistent trim angle. Retaining Ki = 0.40 removes it.

So the ~4 % "improvement" buys nothing a first flight wants and gives up steady-bias rejection. The
firmware gains are kept.

## 5. The real limiter is gimbal authority, not gains

Because peak pitch and steady error are set by the ±5° gimbal against the wind moment, **tuning is
not the lever** at high wind, authority is. This matches the documented low-speed weathercocking of
this vehicle. Practical consequences:

- **Launch-window recommendation: fly in ≤ ~6 m/s wind.** The SIL (`fc_sil.py`) shows boost-phase
  controlled pitch of **0° (calm) → 9.4° (6 m/s) → 21.4° (12 m/s)**; below ~6 m/s the gimbal stays
  out of saturation and the loop tracks tightly.
- **Adopted:** the gimbal throw was raised **±5° → ±8°** (the hardware-authority fix this analysis
  pointed to). That roughly **halves gimbal saturation** (e.g. 6 m/s: 31%→9%; 12 m/s: 52%→35%) and
  lowers high-wind peak pitch (12 m/s: 26°→23°), more authority margin and richer TVC demo data,
  with no change to passive stability. It does **not** change the gains (more authority only adds
  margin). See the weathercocking note in `WYVERN_E4_Stability_FinSizing.md`.

## 6. First-flight readiness

- Gains **Kp 0.10 / Ki 0.40 / Kd 0.18**, frozen in `firmware/gtr70e_wyvern_tvc/wyvern_pid.h`, confirmed by
  frequency-domain margins **and** time-domain robust auto-tune. **No change for first flight.**
- Anti-windup is present (integral clamped to the gimbal limit), so integral is safe even when
  saturated.
- Explore interactively any time in the GUI **PID Tuner** tab (drag gains, watch θ(t)/δ(t) vs. the
  firmware default) and re-run this search from the tab's **Auto-tune** button.

*Reproduce:* `python3 -m wyvern_datagen.pid_autotune` (or `python3 pid_autotune.py` from the package).

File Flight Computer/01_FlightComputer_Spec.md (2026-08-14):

# GTR70E WYVERN, Flight Computer Specification

**Authors:** Swaroop Sahoo, Chris Liu, Allison Hong  
**Program:** GTR70E WYVERN

### Raspberry Pi Pico 2 W on a 20 × 24 perfboard, flight computer *and* real-time TVC controller

Numbers here follow `Documentation/CANONICAL_NUMBERS.md`. Wiring is drawn hole-by-hole in
`wiring/wyvern_perfboard_wiring.svg`; physical placement and the separation-joint cabling are in
`wiring/wyvern_bay_layout.svg`.

## 1. Architecture

A Raspberry Pi Pico 2 W carries the entire avionics load: attitude estimation, the 500 Hz TVC
control law, servo commanding, and logging. It sits on a generic 20 × 24 (50 × 70 mm) perfboard
mounted as an axial card in the Upper BT, held in two slotted carrier disks
(`3D parts/02b_fc_card_carrier_{fwd,aft}_ASAAero`). The 70 mm board length will not fit across the
66.8 mm bore, so it stands on edge; the LiPo straps to its back face and the components stand off
the front.

The RP2350's two cores are partitioned the same way the earlier custom-board design intended:

- **Core 0** runs the control loop exclusively — read IMUs, evaluate PID, command the gimbal
  servos. No blocking operations.
- **Core 1** drains a log ring buffer to microSD over SPI1, keeping storage latency off the
  control path.

Unlike the retired PCB1, the Pico 2 W has a CYW43439 radio. Flight still logs to microSD as the
data of record; WiFi telemetry is enabled only on the ground test stand
(`WYV_WIFI_ENABLED`, defaults to the value of `WYVERN_GROUND_TEST`).

## 2. Sensing

Four Adafruit STEMMA-QT breakouts share one I²C bus on GP0/GP1. No mux, no second bus.

| Device | Role | Address | Strap |
|---|---|---|---|
| BNO085 | Bay attitude, primary control source | 0x4B | DI wired to 3V3 |
| BNO085 | Gimbal-mounted, deflection sensing | 0x4A | DI unconnected (default) |
| BME688 | Primary barometric altitude | 0x76 | SDO wired to GND |
| BMP388 | Backup barometric altitude | 0x77 | SDO unconnected (default) |

Both IMUs run Game Rotation Vector mode — accelerometer/gyro fusion with the magnetometer
disabled, because the gimbal servos sit inches away and would corrupt a magnetically-referenced
heading. The two units vote against each other for attitude fault detection.

Unlike the PCB1 design, the second IMU **is** gimbal-mounted on the flight vehicle, so
gimbal-relative deflection is directly measurable in flight rather than only on the ground rigs.

No external I²C pull-ups are fitted. Each Adafruit breakout carries 10 kΩ; four in parallel give
roughly 2.5 kΩ, which is correct for 400 kHz.

## 3. Pin map

| Pico pin | GPIO | Function |
|---|---|---|
| 1 | GP0 | I²C0 SDA, all four sensors |
| 2 | GP1 | I²C0 SCL, all four sensors |
| 4 | GP2 | Servo 1 signal (pitch) |
| 5 | GP3 | Servo 2 signal (yaw) |
| 11 | GP8 | microSD MISO |
| 12 | GP9 | microSD CS |
| 14 | GP10 | microSD SCK |
| 15 | GP11 | microSD MOSI |
| 31 | GP26 | Battery sense (ADC0) |
| 36 | 3V3 OUT | Sensor rail |
| 39 | VSYS | 5 V from UBEC |
| 3, 8, 13, 18, 23, 28, 33, 38 | GND | Common ground |

Defined once in `firmware/wyvern4_tvc/wyvern_config.h`.

## 4. Power

2S LiPo (7.4 V nominal, 8.4 V full) → PPTC 2.6 A → arming switch → 5 V 3 A switching UBEC.

The UBEC output is the single 5 V rail: Pico VSYS, the microSD breakout, and both servos. Sensors
run off the Pico's own 3V3 regulator. A 470 µF electrolytic sits at the servo feed — without it a
simultaneous servo stall browns out the Pico.

The arming switch is reached by pulling the nose cone, so there is no hole in the Upper BT and no
switch cutout in the CAD. It carries full pack current (about 1.9 A worst case at the 6.0 V
cutoff) plus inrush into the UBEC and bulk capacitance, which is why it is a 20 A-class switch
rather than a micro slide switch.

Battery sense is a 100 kΩ / 47 kΩ divider from the armed pack rail to GP26, with 100 nF on the
tap: 2.686 V at 8.4 V, 1.918 V at the 6.0 V cutoff, both inside the ADC range. Firmware thresholds
are 6.4 V warn / 6.0 V critical.

## 5. Separation

The Upper BT and Lower BT part at the bulkhead when the F15-4 ejection charge fires at t = 7.45 s.
Seven leads cross that joint on dupont male-female extensions and simply pull apart:

SERVO1_SIG · SERVO2_SIG · +5V · GND · SDA · SCL · 3V3

Only the aramid shock cord is retained. Bulkhead pass-throughs (4.5 mm and 4.0 mm) are sized for
the wire bundles, not the connector shells — the dupont housings sit either side so they part
freely.

Consequences the firmware handles explicitly:

- TVC is finished at burnout (3.45 s), four seconds before separation, so losing servo power costs
  nothing.
- The gimbal IMU leaves with the Lower BT. `TriImu::mark_separated()` stops reporting its absence
  as a fault after `WYV_DEPLOY_T_MS`; before that point it is still a genuine fault.
- Descent attitude comes from the bay unit, which never crosses the joint.
- `WYV_I2C_TIMEOUT_US` bounds every transaction. A read to the now-absent 0x4A must NACK, not
  block — otherwise the loop stalls exactly when descent logging matters.

## 6. Dual role, flight and ground stand

The same board and the same firmware image serve the ground TVC/servo test stand. Set
`WYVERN_GROUND_TEST` to 1 and:

- The bay IMU is not required — `begin()` reports it present so the 2-of-2 gate passes on a stand
  that physically has one IMU
- `body_accel_mag_g()` returns a resting 1 g, so launch-detect and landing-quiescence cannot trip
- Launch detection and recovery logic compile out
- WiFi telemetry enables, since a bench has no reason to log blind

Attitude on the stand comes solely from the gimbal unit, which is the thing the stand exists to
measure.

## 7. Control law

Discrete PID per axis with integral anti-windup clamping and a first-order low-pass-filtered
derivative, at 500 Hz, output clipped to ±8° gimbal deflection.

Flight gains: Kp = 0.10, Ki = 0.40, Kd = 0.18, τ_d = 0.02 s. Selected by a 24-point phase/gain
margin sweep (phase margin ≈ 33°, gain margin ≈ 12.6 dB) and confirmed by a time-domain
multi-wind auto-tune. The TVC loop is inhibited for the first 0.5 s, after which it stabilises to
vertical and executes a commanded maneuver.

## 8. Why the Pico 2 W

The custom PCB1 (Ø62 mm, bare RP2350B QFN-80) was retired on schedule and cost grounds: a 0.4 mm
pitch QFN needs a 4-layer board with a solid ground plane, and the layout work plus fab turnaround
did not fit the November launch window.

| | PCB1 (retired) | Pico 2 W perfboard |
|---|---|---|
| MCU | Bare RP2350B, QFN-80 | Pico 2 W module (RP2350) |
| Cores | 2 × 150 MHz M33 | 2 × 150 MHz M33 |
| Radio | None populated | CYW43439, bench use |
| Assembly | 4-layer PCB fab + reflow | Perfboard, hand-soldered |
| Bring-up risk | Whole board, one shot | Per-breakout, incremental |
| Mass | ~14 g board | ~11 g board + 4 g Pico |
| Lead time | Fab turnaround | On hand |

Control-loop capability is identical — same silicon, same core split, same 500 Hz. What was lost
is board density and the INA226 current monitor; battery monitoring is now a resistor divider on
GP26.

## References

Bosch Sensortec. (n.d.). *BNO085 9-axis absolute orientation IMU, datasheet.*

Bosch Sensortec. (n.d.). *BME688 gas, pressure, humidity, temperature sensor, datasheet.*

Bosch Sensortec. (n.d.). *BMP388 digital pressure sensor, datasheet.*

Raspberry Pi Ltd. (2024). *Raspberry Pi Pico 2 W datasheet.*

Raspberry Pi Ltd. (2024). *RP2350 datasheet.*

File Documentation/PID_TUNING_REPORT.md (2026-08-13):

# GTR70E WYVERN, Pitch/Yaw TVC PID Re-Tune Report

**Authors:** Swaroop Sahoo, Chris Liu, Allison Hong  
**Program:** GTR70E WYVERN

**Result: firmware gains changed from Kp=2.0/Ki=0.4/Kd=0.5 to Kp=0.10/Ki=0.40/Kd=0.18.**
Both `Flight Computer/firmware/wyvern_pid.h` and `Simulations/pid_reference.py` now implement the
new gains. Full derivation code: `Simulations/we4_pid_retune.py`. Report figure:
`PID_TUNING_REPORT.png`.

## 1. Why the previous gains were re-checked

The pitch/yaw TVC loop had already been tuned once: `Simulations/we4_atmos_tvc.py`'s nonlinear
closed-loop sim showed the flowchart's Kp=8/Ki=1.5/Kd=1.2 ringing against the ~40 ms servo lag, and
Kp=2.0/Ki=0.4/Kd=0.5 was adopted instead as "well-damped." That sim is a genuine nonlinear
time-domain model (fin aero restoring + damping, thrust curve, 4 atmospheres, two 1-cosine gusts)
, but it has **no explicit model of the digital control loop's computational/actuation delay**. In
a 500 Hz (2 ms period) loop, the output computed from a sample is applied roughly one sample later;
that delay adds phase lag that a delay-free nonlinear sim cannot see.

To close that gap, the pitch plant was linearized and analyzed with classical frequency-domain
stability margins (phase margin, gain margin) using the `python-control` library, with the 2 ms
loop delay modeled explicitly as a 2nd-order Padé approximant in series with the existing 40 ms
servo lag.

## 2. Linearized plant

At a given point in the burn, small-signal pitch dynamics are:

```
I·θ̈ = T·sin(δ)·(x_gimbal − CG) − q·A·C_N·(Xcp − CG)·θ − q·A·C_N·(Xcp − CG)²/v·θ̇
        └────────── TVC moment ──────────┘ └── aero restoring ──┘ └──── aero damping ────┘
```

giving a transfer function θ(s)/δ(s) = b / (I·s² + c·s + k), where `b` (control effectiveness),
`k` (aero restoring stiffness) and `c` (aero damping) all vary with dynamic pressure `q = ½ρv²` and
thrust `T`, both of which change through the burn and across atmospheres. `I = 0.0323 kg·m²` is the
fixed slender-body pitch inertia.

**24 operating points** were extracted from the existing `we4_atmos_tvc.py` trajectories: the 4
flight atmospheres (ISA 15°C, Cold −15°C, Hot +40°C, High-DA 1500 m) × 6 burn-time slices (0.6,
1.0, 1.7, 2.5, 2.9, 3.4 s), covering the full swing from low-*q*/high-thrust early burn to
high-*q*/low-thrust tail-out. Representative values (ISA):

| t (s) | v (m/s) | q (Pa) | T (N) | b (control eff.) | k (aero stiffness) |
|---|---|---|---|---|---|
| 0.6 | 10.2 | 63 | 15.2 | 3.86 | 0.034 |
| 1.7 | 22.3 | 305 | 14.3 | 3.62 | 0.164 |
| 2.9 | 33.9 | 700 | 13.7 | 3.46 | 0.377 |
| 3.4 | 35.7 | 777 | 2.8 | 0.70 | 0.419 |

The open loop at each point is `PID(s) · servo_lag(s) · loop_delay(s) · plant(s)`, with
`servo_lag(s) = 1/(0.04s+1)`, `loop_delay(s)` a 2nd-order Padé model of a 2 ms pure delay, and the
PID including its filtered-derivative pole (`tau_d = 0.02 s`, matching firmware).

## 3. The old gains fail the margin check

At every one of the 24 operating points, Kp=2.0/Ki=0.4/Kd=0.5 was evaluated for phase margin (PM)
and gain margin (GM). Worst case (Cold −15°C, t=0.6 s into burn, low-*q*/high-authority):

| Gains | Worst-case PM | Worst-case GM |
|---|---|---|
| Kp=2.0 Ki=0.4 Kd=0.5 (old) | **−0.1°** | **−0.0 dB** |
| Kp=0.10 Ki=0.40 Kd=0.18 (new) | **+44.1°** | **+12.6 dB** |

Negative margin means the closed-loop poles are in the right half-plane at that operating point, 
genuinely unstable, not merely lightly damped. Re-running the *nonlinear* time-domain gust test
with the old gains (now correctly showing the effect once the analysis includes delay) exhibits
sustained, undamped gimbal oscillation late in the burn (see figure, panel B/C, red trace), a
symptom consistent with the predicted instability, distinct from a stable-but-underdamped ring.

## 4. Gain search and selection

Gains were swept on a grid (~37,000 (Kp,Ki,Kd) triples evaluated across successive refinement
passes, from a coarse P/PI/PID scan down to a fine local grid around the surviving region), keeping
only triples whose **worst-case margin across all 24 operating points** clears the classical
minimum for flight control loops: **phase margin ≥ 30°, gain margin ≥ 6 dB**. Margin-safe triples
were then re-evaluated in the full nonlinear time-domain sim (servo lag, fin aero, 1-cosine 6–7 m/s
gust, all 4 atmospheres) and ranked by worst-case gust-rejection pitch deviation, discarding any
that still exhibited gimbal chatter (>4 sign changes in gimbal rate during steady flight, a
proxy for a lightly-damped or borderline oscillatory mode that the linear margin alone can miss
near the classification boundary).

**Selected: Kp = 0.10, Ki = 0.40, Kd = 0.18** (out_lim = 5°, tau_d = 0.02 s, i_lim = 0.4, unchanged
from before).

| Metric | Old (Kp=2.0/Ki=0.4/Kd=0.5) | New (Kp=0.10/Ki=0.40/Kd=0.18) |
|---|---|---|
| Worst-case phase margin | −0.1° (unstable) | +44.1° |
| Worst-case gain margin | −0.0 dB (unstable) | +12.6 dB |
| Worst-case gust pitch deviation | 0.43° (misleadingly good, delay-free sim) | 1.96° |
| Worst-case gimbal usage | up to 1.98° (chattering) | 2.35° (smooth) |
| 2° step: rise time | ~273 ms | ~1037 ms |
| 2° step: overshoot | ~11.9% (rings) | ~3.4% (clean) |
| 2° step: gimbal-rate zero-crossings, t>2s | 12 (chatter) | 2 (normal) |

The new gains are markedly slower (rise time roughly 4× longer) and lower-bandwidth than the old
ones. This is the expected, deliberate trade: the old gains' apparent speed was purchased by
running close to (in fact past) the stability boundary once actuation delay is accounted for. The
new gains keep worst-case gust pitch deviation under 1.4° and gimbal deflection well inside the ±8°
mechanical limit, with margin to spare, across the full 4-atmosphere × 6-burn-time envelope.

## 5. Caveats and follow-ups

- The plant linearization assumes small-angle aero terms and treats `b`, `k`, `c` as static at each
  op point (frozen-coefficient / quasi-LPV analysis) rather than a single time-varying LTI model;
  this is standard practice for gain-margin analysis of slowly-varying plants and is justified here
  because the coefficients vary slowly relative to the loop bandwidth, but a full LPV or
  Floquet-style analysis would be a stronger guarantee.
- The 2 ms loop delay is modeled generically as "one sample of computational/actuation lag"; if the
  real firmware's sensor-read → PID → PWM-write path measurably differs from one full 2 ms tick,
  the delay parameter should be re-measured on hardware and the sweep re-run.
- Yaw is assumed identical to pitch (symmetric vehicle, decoupled planes) per the existing
  simulation's convention; this was not independently re-verified.
- Recommend a bench validation (servo + IMU on the bench, `test_code/t3_servo_sweep.ino` style
  step/impulse test) before first flight, to confirm the 40 ms servo lag and loop-delay assumptions
  match the actual hardware.

## 6. Reproducing this analysis

```
cd Simulations
python3 we4_pid_retune.py # margin sweep + selection -> pid_retune_summary.json
python3 pid_reference.py # quick step-response sanity check with the new gains
python3 we4_atmos_tvc.py # full nonlinear 4-atmosphere closed-loop validation
```

Requires `numpy`, `scipy`, and `python-control` (`pip install control`).

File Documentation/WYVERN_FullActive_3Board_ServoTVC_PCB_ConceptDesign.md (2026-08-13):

# WYVERN, Full Active-Control Avionics Stack, Rev 2

**Authors:** Swaroop Sahoo, Chris Liu, Allison Hong  
**Program:** GTR70E WYVERN

##### Three 75 mm circular boards, stacked: Camera/Sensor/Airbrake, Compute/Power/Storage, TVC/Fin/Sensor
##### Concept + component-level BOM only. No schematic, footprint, or routing generated, staged for the AI PCB design tool.

## 0. What changed from Rev 1

Board diameter is fixed at 75 mm (matching the GTR70E WYVERN 2.0 FCM/B1/B2 precedent, Ø69 mm
4×M3 mount pattern, 2-layer or 4-layer FR4, ENIG). Stack order and board assignments are now
fixed per Sky's spec below. The Pocket Geiger module is cut, it's a pre-built breakout board,
not a placeable component, and Sky's rule this pass is that only the camera, the NVMe drive,
and the servos are allowed to live off the PCB as connectorized modules. Everything else has to
be a real part JLCPCB can place. Radiation sensing can come back later as a bare PIN photodiode
+ discrete charge-amp front end (a real from-scratch circuit, not a module) if it's wanted, not
included here since it wasn't asked for this pass.

## 1. Stack order and board roles

```
   ┌─────────────────────────────┐
   │ BOARD 1, Camera / Sensor / │ (top disc)
   │ Airbrake Driver │
   ├─────────────────────────────┤ 2x10 stack header (B1↔B2) + CSI flex jumper
   │ BOARD 2, Compute / Power / │ (middle disc)
   │ Storage / Comms │
   ├─────────────────────────────┤ 2x10 stack header (B2↔B3)
   │ BOARD 3, TVC / Fin Driver / │ (bottom disc)
   │ Remaining Sensors / Mic │
   └─────────────────────────────┘
```

All three boards: Ø75.0 mm (r = 37.5 mm) circular Edge.Cuts, 4×M3 mounts on Ø69 mm at
0/90/180/270°, matching the GTR70E WYVERN 2.0 stack so the same disc-mount hardware carries over.

## 2. Board 1, Camera / Sensor / Airbrake driver (top)

### 2.1 Camera interface
Raspberry Pi Camera Module 3 (12 MP, autofocus, CSI-2) plugs into a 22-pin, 0.5 mm pitch FPC
connector on Board 1. Because CSI-2 is a high-speed differential MIPI link and the camera's
actual processor (CM5) sits one disc down on Board 2, the connector-to-connector run is a
dedicated short FPC/flex jumper between B1 and B2, kept physically and electrically separate
from the general-purpose 2×10 stack header, since MIPI shouldn't share a connector with slow
GPIO/I2C nets. This is the one interconnect on the stack that needs real signal-integrity
attention from the AI PCB tool (controlled length, controlled impedance, minimal stack gap).

### 2.2 Sensor suite (most of the suite lives here)
| Function | Part | Interface | Package |
|---|---|---|---|
| Barometric altimeter | Bosch BMP390, ±3 cm resolution | I2C | LGA-10 |
| Temp / humidity / gas (VOC index) | Bosch BME680 | I2C | LGA-8 |
| Calibrated CO2 (NDIR) | Sensirion SCD41, 400–5000 ppm, ±(50 ppm+5%) | I2C | 10.1×10.1×6.5 mm LGA |
| Redundant magnetometer | ST LIS3MDL | I2C | LGA-12 |
| Bus current/voltage, airbrake rail | TI INA226, 16-bit, 0.1% gain error, 10 mΩ shunt | I2C | SOT-23-8 |

### 2.3 Airbrake servo drive (2 channels)
The PWM origin is the RP2350B on Board 3 (keeps a single deterministic timing source for every
servo on the vehicle). Board 1 hosts the physical actuator interface per channel: JR/Futaba
3-pin connector, local 100 nF + 10 µF decoupling at the connector, and a gate-driven low-side
FET stage if current limiting is wanted per channel. PWM commands cross the stack from Board 3
through Board 2 on two dedicated single-ended lines in the general 2×10 headers, a GPIO toggle
at ≤50 Hz update rate has no bandwidth concern crossing two connectors (same principle validated
in the GTR70E WYVERN 2.0 two-board spec for the solenoid PWM lines).

| Channel | Connector | Servo (off-board) |
|---|---|---|
| Airbrake 1 | J-AB1, JR/Futaba 3-pin | Savöx SH-0257MG, 3.5 kg·cm, 11.4 g |
| Airbrake 2 | J-AB2, JR/Futaba 3-pin | Savöx SH-0257MG |

### 2.4 Power on Board 1
Local 3.3 V TPS54202 buck off the B1↔B2 stack's 5 V rail, feeding the I2C sensor suite. Servo
connectors draw off the shared 5 V servo rail (sourced on Board 2, see §3.3) passed through the
stack header, with local bulk capacitance (2× 470 µF) at the airbrake connectors to absorb
switching transients without sagging the shared rail.

## 3. Board 2, Compute / Power / Storage / Comms (middle)

Middle position is deliberate: this disc carries the pack input and both USB-C ports, so it
sits at the mechanical/electrical center of the stack, and it's the shortest path for the
CSI flex jumper (up to B1) and the PCIe run to the NVMe socket (local, no stack crossing).

### 3.1 Compute + RAM
Raspberry Pi Compute Module 5 (8 GB LPDDR4X, quad Cortex-A76 @ 2.4 GHz, PCIe Gen2 x1, dual
4-lane MIPI, 2× USB 3.0) [1], mounted via its Hirose DF40C-100DS/DP-0.4 mm edge connector pair, 
this is the JLCPCB-compatible equivalent of the camera/NVMe/servo exception: the CM5 module
itself plugs in, but the connector, PMIC support circuitry, and every passive around it are real
placed parts. *If Sky wants true silicon-level integration instead of a pluggable SoM* (bare
Rockchip RK3588S or similar BGA SoC + discrete LPDDR4X + eMMC boot flash + PMIC sequencing),
that's a legitimate alternate path but is a multi-month professional SI/PCB bring-up in its own
right, not a concept-design-scope swap, flag if that's actually what's wanted and it becomes
its own design pass.

### 3.2 Storage
M.2 Key-M socket (2230/2242/2280 switch-selectable mounting holes, populated with a 2230 drive)
wired to CM5's single PCIe x1 lane, kept local to Board 2, no PCIe crossing the stack.

### 3.3 Power front end and servo/logic rails
- XT30 12 V-in connector (matches the project's existing 12 V pack convention), 1812 PPTC
  fuse, high-side reverse-polarity P-FET, SMBJ-class TVS clamp.
- TI BQ25792, I2C 1S–4S buck-boost charger, 5 A max charge, USB-C PD 3.0 sink negotiation,
  96.5% efficiency at 9 V-in/3 A on a multi-cell pack [2]. Charges the same XT30 pack the
  vehicle flies on through USB-C PD, no separate balance port.
- 5 V servo rail: synchronous buck (MP2338-class, 8 A peak) sized for the worst-case 9-servo
  simultaneous stall (~10.8 A instantaneous per Savöx SH-0257MG stall spec, duty-cycled in
  normal flight); 3× 470 µF bulk at the rail's stack-header exit point.
- 5 V compute rail: separate 3 A buck for CM5 + NVMe + camera, isolated from servo rail
  transients.
- 3.3 V logic rail: TPS54202 for RP2350B (Board 3) and both sensor boards' I2C pull-ups.
- INA226 on the battery input (pack-level current/voltage telemetry).

### 3.4 USB-C ports (2×, physically separate)
| Port | Function | Routed to |
|---|---|---|
| USB-C #1 | PD charge-in only | BQ25792 |
| USB-C #2 | Data (ground data pull, flashing) | CM5 USB 3.0 |

Charge and data stay on physically separate connectors and separate silicon, a ground-support
laptop is never electrically in the battery's charge path.

### 3.5 "Critical sensors for control"
Placed on the middle disc deliberately: this is the position closest to the vehicle's
center of gravity, which is where the primary attitude reference belongs for best measurement
fidelity, independent of which board hosts the MCU driving the control loop.

| Function | Part | Interface |
|---|---|---|
| Fast-loop 6-DoF (rate gyro/accel) | TDK ICM-42688-P, 32 kHz ODR | SPI, routed to RP2350B on Board 3 over the B2↔B3 stack header |
| Fused 9-DoF orientation reference | Bosch BNO085, SH-2 fusion, quaternion out | I2C, shared bus to Board 3 |

The ICM-42688-P's SPI link crossing one stack connector (B2→B3) is the one place this Rev
departs from the "keep the fast-loop sensor local to the MCU" principle used in GTR70E WYVERN 2.0, 
that's the direct consequence of Sky's placement call (CG-proximity for the sensor beats
zero-latency wiring). One connector hop at SPI clock rates well under 24 MHz is still a small
fraction of a 500 Hz control loop's budget, but it's worth the AI PCB tool giving that link
priority in the header pinout (short, low-inductance path, adjacent-GND-pin shielding).

## 4. Board 3, TVC / Fin driver / remaining sensors / mic (bottom)

### 4.1 Compute
RP2350B (QFN-80-1EP, dual Cortex-M33 @ 150 MHz, 48 GPIO, 12 PWM slices/24 channels, 520 kB
SRAM) [3], the real-time core for the whole servo stack. Lives here because this disc carries
7 of the 9 servo channels (the highest channel count and the tightest timing requirement, the
3-axis TVC gimbal), so the MCU sits closest to the load it directly times.

### 4.2 Servo drive (7 channels, direct off RP2350B PWM slices)
| Channel group | Qty | GPIO | Servo (off-board) |
|---|---:|---|---|
| TVC gimbal (3-axis) | 3 | GPIO30–32 | Savöx SH-0257MG |
| Active fins (N/E/S/W) | 4 | GPIO33–36 | Savöx SH-0257MG |

Plus GPIO37–38 generating the 2 airbrake PWM signals routed up to Board 1 through Board 2
(§2.3). Each of the 7 local channels: JR/Futaba 3-pin connector, local decoupling, shared 5 V
servo rail (from Board 2) with 3× 470 µF bulk at this board's rail entry point given it carries
the largest simultaneous-load channel group.

### 4.3 Remaining sensors + mic
| Function | Part | Interface |
|---|---|---|
| Bus current/voltage, TVC+fin rail | TI INA226 | I2C |
| Acoustic / launch signature | Infineon IM69D130 MEMS mic, 105 dB dynamic range, up to 130 dB SPL [4] | PDM → ADAU7002 PDM-to-I2S bridge → I2S to RP2350B |

### 4.4 Power on Board 3
3.3 V logic rail entry (from Board 2) for RP2350B and the local sensors; 5 V servo rail entry
(from Board 2) for the 7 local channels. No local regulation beyond decoupling, both rails are
generated once, on Board 2, and distributed through the stack headers to avoid duplicate
converters and duplicate EMI sources.

## 5. Inter-board connectors

| Link | Connector | Carries |
|---|---|---|
| B1 ↔ B2 | 2×10 (20-pin), 2.54 mm, 6 dedicated GND pins interleaved | I2C (shared sensor bus), 2× airbrake PWM, 3V3, 5V_SERVO, GND |
| B1 ↔ B2 (separate) | 22-pin 0.5 mm FPC/flex jumper | MIPI CSI-2 (camera ↔ CM5), kept off the general header, SI-critical |
| B2 ↔ B3 | 2×10 (20-pin), 2.54 mm, 6 dedicated GND pins interleaved | SPI (ICM-42688-P), I2C (BNO085 + shared bus), 3V3, 5V_SERVO, GND, UART (RP2350B ↔ CM5 telemetry handoff) |

## 6. JLCPCB fabrication targets (per board, first-pass, to be confirmed once routed)

| Parameter | Board 1 | Board 2 | Board 3 |
|---|---|---|---|
| Diameter | 75.0 mm | 75.0 mm | 75.0 mm |
| Layers | 2 | 4 (Sig/GND/PWR/Sig) | 2 |
| Finish | ENIG | ENIG | ENIG |
| Min trace/space | ≥0.127 mm | ≥0.127 mm | ≥0.127 mm |
| Min via / drill | ≥0.45/0.2 mm | ≥0.45/0.2 mm | ≥0.45/0.2 mm |
| Mount pattern | 4×M3, Ø69 mm | 4×M3, Ø69 mm | 4×M3, Ø69 mm |

Board 2 gets 4 layers because it's carrying PCIe (NVMe), the CM5 high-density edge connector
fanout, and the charger's higher-current power distribution, the same justification the
GTR70E WYVERN 2.0 spec used for its Board 2 (RP2350B + camera board) 4-layer stackup.

## 7. Power budget

| Rail | Source (Board 2) | Continuous | Peak |
|---|---|---:|---:|
| 5 V servo (all 9 channels) | MP2338-class buck, 8 A peak | ~2–3 A duty-cycled | 10.8 A (9× simultaneous stall) |
| 5 V compute | Dedicated 3 A buck | 1.5–2 A | 3 A |
| 3.3 V logic | TPS54202 | 250 mA | 400 mA |
| USB-C PD charge-in | BQ25792, 5 A max | — | 3 A @ 9 V, 96.5% eff. |

## 8. What's deliberately not done yet

No schematic, no footprints, no routed copper, this document is the component list, board
assignment, physical stack geometry, and inter-board net list only, per the instruction to hand
this straight to the AI PCB design tool rather than hand-drafting KiCad. The one item that tool
should be told to treat specially is the CSI flex jumper in §2.1/§5, everything else is
conventional 2.54 mm header + standard passive/IC placement.

## 9. Citations

[1] Raspberry Pi Ltd, Compute Module 5 Datasheet, PCIe Gen2 x1, dual MIPI, 8 GB LPDDR4X, 
https://datasheets.raspberrypi.com/cm5/cm5-datasheet.pdf
[2] Texas Instruments BQ25792 datasheet, 1–4 cell buck-boost charger, USB PD 3.0, 
https://www.ti.com/lit/ds/symlink/bq25792.pdf
[3] Raspberry Pi Ltd, RP2350 Datasheet, PWM (12 slices/24 channels), GPIO, 520 kB SRAM, 
https://datasheets.raspberrypi.com/rp2350/rp2350-datasheet.pdf
[4] Infineon IM69D130 datasheet, 105 dB dynamic range MEMS microphone, 
https://www.infineon.com/assets/row/public/documents/24/49/infineon-im69d130-datasheet-en.pdf

Other parts (BMP390, BME680, SCD41, LIS3MDL, ICM-42688-P, BNO085, INA226, Savöx SH-0257MG,
TPS54202) carry forward from Rev 1's citation list and the GTR70E WYVERN 2.0 board precedent, same
parts, same sourcing, just reassigned across the new three-board split.

## References

CEVA, Inc. (2023). *BNO08X datasheet* (Rev. 1.17). https://www.ceva-ip.com/wp-content/uploads/BNO080_085-Datasheet.pdf

EMAX. (n.d.). *ES08MA II 12 g mini metal gear analog servo* [Product specification]. Retrieved August 12, 2026, from https://www.getfpv.com/emax-es08ma-ii-12g-mini-metal-gear-analog-servo-for-rc-model.html

Estes Industries. (n.d.). *F15-4 engines* [Product specification]. Retrieved August 12, 2026, from https://estesrockets.com/products/f15-4-engines

Federal Aviation Administration. (n.d.). *14 CFR Part 101 — Moored balloons, kites, amateur rockets, and unmanned free balloons*. Electronic Code of Federal Regulations. https://www.ecfr.gov/current/title-14/chapter-I/subchapter-F/part-101

National Fire Protection Association. (2018). *NFPA 1122: Code for model rocketry*. https://www.nfpa.org/product/nfpa-1122-code/p1122code

Raspberry Pi Ltd. (2024). *RP2350 datasheet*. https://datasheets.raspberrypi.com/rp2350/rp2350-datasheet.pdf

Texas Instruments. (n.d.). *TPS564201: 4.5-V to 17-V input, 4-A synchronous step-down voltage regulator* (SLVSFB5) [Datasheet]. https://www.ti.com/lit/ds/symlink/tps564201.pdf

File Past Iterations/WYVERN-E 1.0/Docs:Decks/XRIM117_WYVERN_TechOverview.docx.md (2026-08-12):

---
source_file: "XRIM117_WYVERN_TechOverview.docx"
source_type: "DOCX"
updated_at: 2026-05-26
---
# XRIM117_WYVERN_TechOverview

*Extracted from [[XRIM117_WYVERN_TechOverview.docx]]*

---

**XRIM-117 WYVERN**

Technology Overview --- Companion Document

**Prototype Technology Demonstrator · PDR-002 Rev A**

Skylight Industries LLC

**CONFIDENTIAL --- FOR DISCUSSION PURPOSES ONLY --- NOT FOR DISTRIBUTION**

1\. Executive Summary

The XRIM-117 WYVERN Prototype Technology Demonstrator (PTD) is a 70mm-diameter autonomous guided rocket platform developed by Skylight Industries LLC to validate a hybrid flight-control architecture in a recoverable, repeatably-flyable subscale vehicle. The programme uses commercially available hobby rocketry hardware, custom-designed electronics, and PETG-CF printed structure throughout.

The vehicle integrates two independent rings of four aerodynamic control fins with a ceramic jetavane thrust-vector control system --- a novel approach at hobby scale that simultaneously provides attitude control and analogue thrust modulation from the same actuator. A three-board distributed avionics stack with redundant inertial measurement and independent power domains handles all flight-critical functions autonomously, with real-time datalink to a ground control station.

  --------------------------- --------------------------------------------------------------------------------
  **Programme designation**   XRIM-117 WYVERN PTD PDR-002 Rev A
  **Organisation**            Skylight Industries LLC
  **Vehicle class**           Subscale autonomous guided demonstrator --- hobby motor propulsion
  **Primary objective**       Validate hybrid aerodynamic + TVC control architecture in powered flight
  **Scale**                   1:2.14 geometric scale
  **Body diameter**           70mm OD / 68mm ID
  **Overall length**          \~1,170mm
  **All-up mass (est.)**      \~640g
  **Propulsion**              Two-stage commercial solid motors --- 29mm booster + 38mm sustainer
  **Launch mode**             1010 aluminium extrusion rail, near-vertical, 1.83m
  **Recovery**                Computer-triggered ejection charge --- nose cone separation --- 24in parachute
  **Datalink**                915MHz LoRa --- \~2km line-of-sight
  **Build cost (est.)**       \~\$660 USD per vehicle (one-time PCB setup included)
  --------------------------- --------------------------------------------------------------------------------

2\. Vehicle Architecture

2.1 Airframe
------------

The primary structure is a PETG-CF 20% carbon-fibre-reinforced printed outer shell laminated over a 70mm OD / 68mm ID phenolic tube liner that provides the structural backbone. All external aerodynamic and structural components --- fin cans, centering rings, nose cone, TVC frame, and avionics sled --- are printed in PETG-CF. The avionics sled and nose bay use PLA where thermal loading is not a concern.
---------------------------------------------------------------------------------------------------------------------------------------------------------------------------------------------------------------------------------------------------------------------------------------------------------------------------------------------------------------------------------------------------------------------

  ------------------------- -------------------------------------------------------------------------
  **Body tube**             70mm OD / 68mm ID phenolic liner + PETG-CF 20% CF outer shell
  **Overall length**        \~1,170mm across three bolted sections
  **Forward section**       \~270mm --- nose cone bay + parachute bay
  **Mid section**           \~490mm --- CCM avionics sled + ASAM-1 + mid fin ring
  **Aft section**           \~410mm --- ASAM-2 + 38mm sustainer + jetavane + aft fin ring + booster
  **Nose cone profile**     Von Karman ogive (Haack LV series), 234mm, PETG-CF
  **Section coupling**      PETG-CF centering rings + M3 nylon-tipped set screws per joint
  **Print specification**   0.2mm layer height, 3--4 perimeter walls, 40--60% gyroid infill
  ------------------------- -------------------------------------------------------------------------

2.2 Aerodynamic Control Surfaces
--------------------------------

One active ring of four all-moving mid fins provides primary pitch, yaw, and roll authority. Ring 1 (aft stabilisers) is passive --- four fixed fins bonded into the aft fin can provide baseline aerodynamic stability without active control. Ring 2 (mid canard-style fins, clocked 45° to Ring 1) provides primary pitch, yaw, and roll authority at speed. The four Ring 2 fins are independently servo-actuated on a 7.4V high-voltage rail; Ring 1 is fixed (no servos).
-------------------------------------------------------------------------------------------------------------------------------------------------------------------------------------------------------------------------------------------------------------------------------------------------------------------------------------------------------------------------------------------------------------------------------------------------------------------------------

  ------------------ --------------------------------------- ------------------------------------------
  **Parameter**      **Ring 1 --- Aft Stabilisers**          **Ring 2 --- Mid Control Fins**
  Quantity           4, at 90° spacing                       4, at 90° spacing, clocked 45° to Ring 1
  Root chord         93mm                                    47mm
  Tip chord          47mm                                    23mm
  Span               70mm                                    35mm
  Actuation          None --- fixed bonded root (no servo)   KST X08 Plus HV --- 1 servo per fin
  Max deflection     0° (fixed)                              ±25°
  Pivot axis         None --- epoxy-bonded into fin can      50% chord
  Servo controller   None --- no PWM channels required       ASAM-1 (TIM1\_CH1--4)
  ------------------ --------------------------------------- ------------------------------------------

3\. Propulsion System

3.1 Two-Stage Architecture
--------------------------

Stage 1 (29mm booster) accelerates the vehicle off the rail. At burnout, a spring-loaded ejection ring separates the booster casing rearward --- the casing deploys a streamer and descends separately. Stage 2 (38mm sustainer) provides thrust for altitude hold, loiter, and the landing burn, operating through the ceramic jetavane TVC system.
----------------------------------------------------------------------------------------------------------------------------------------------------------------------------------------------------------------------------------------------------------------------------------------------------------------------------------------------------

  --------------------- --------------------------------------- ----------------------------------------
  **Parameter**         **Stage 1 --- Booster (29mm)**          **Stage 2 --- Sustainer (38mm)**
  Motor class           F impulse --- commercial hobby reload   G impulse --- commercial hobby reload
  Candidate (nominal)   Cesaroni F39-6T                         AeroTech G76-10G (\~10s burn, avg 76N)
  Total impulse         80--120 N·s                             \~637 N·s (G76)
  TVC                   None --- fixed mount                    Ceramic jetavane [±]{dir="rtl"}45°
  Retention             Eject-design --- no aft retainer        Aeropack 38mm threaded retainer
  Recovery              Streamer via ejection charge            Sustainer section --- main parachute
  --------------------- --------------------------------------- ----------------------------------------

3.2 Ceramic Jetavane TVC System
-------------------------------

The sustainer TVC system uses two ceramic jetavanes --- one per axis (pitch, yaw) --- mounted inside the nozzle diverging section on titanium pivot shafts. Each vane is independently servo-driven by ASAM-2 and rotates up to [±]{dir="rtl"}45° from the flow axis. This simultaneously deflects the exhaust vector for attitude control and partially occludes the nozzle exit area to reduce effective thrust --- providing analogue throttle authority over the otherwise fixed-thrust motor. The motor mount is fixed; no outer gimbal ring is required.
--------------------------------------------------------------------------------------------------------------------------------------------------------------------------------------------------------------------------------------------------------------------------------------------------------------------------------------------------------------------------------------------------------------------------------------------------------------------------------------------------------------------------------------------------------------

⚠ *Jetavane TVC is the operating principle used in the V-2 (1942) and numerous early surface-to-air missile systems. Graphite vanes were standard in those applications; WYVERN uses Macor machinable glass-ceramic, which handles 1000°C continuous service temperature --- adequate for hobby solid motor burn durations under 10 seconds.*
---------------------------------------------------------------------------------------------------------------------------------------------------------------------------------------------------------------------------------------------------------------------------------------------------------------------------------------------

  ------------------------- ----------------------------------------------------------------------------------------
  **Vane material**         Macor machinable glass-ceramic (prototyping) / ZTA zirconia-toughened alumina (flight)
  **Max service temp**      Macor: 1000°C · ZTA: 1500°C · Nozzle diverging-section wall: \~800--1200°C
  **Vane geometry**         \~12mm wide × 22mm tall × 3mm thick rectangular plate
  **Pivot shaft**           3mm titanium rod through nozzle wall, sealed with high-temp RTV
  **Actuators (×2)**        KST X08 Plus HV · TIM2\_CH1 (pitch) · TIM2\_CH2 (yaw) on ASAM-2 7.4V HV rail
  **Deflection range**      [±]{dir="rtl"}45° vane rotation · \~20° effective exhaust deflection at max angle
  **Thrust modulation**     0° → \~100% rated thrust [· ±]{dir="rtl"}45° → \~35% rated thrust
  **Fail-safe**             Spring return to 0° on servo power loss --- full thrust, neutral vector
  **Impulse loss (est.)**   \~3--5% of total impulse due to vane drag --- acceptable for demonstrator
  ------------------------- ----------------------------------------------------------------------------------------

4\. Avionics Architecture

4.1 Three-Board Distributed Stack
---------------------------------

The avionics architecture distributes flight-critical functions across three 62mm circular custom PCBs, each with its own LiPo power source and redundant sensor suite. This eliminates single-board failure as a mission-ending event and allows parallel testing of each module independently.
------------------------------------------------------------------------------------------------------------------------------------------------------------------------------------------------------------------------------------------------------------------------------------------------

  ----------- ----------- ------------------------------------------------------------- ------------------- -------------
  **Board**   **MCU**     **Primary function**                                          **Servo outputs**   **Battery**
  CCM         RP2040      Guidance, LoRa datalink, 3× pyro MOSFET                       None                1S 850mAh
  ASAM-1      STM32F411   Mid ring fins, redundant IMU+baro                             4× Ring 2 fins      1S 1000mAh
  ASAM-2      STM32F411   Jetavane TVC, sustainer relay (Ring 1 aft fins are passive)   2× jetavane         1S 1200mAh
  ----------- ----------- ------------------------------------------------------------- ------------------- -------------

4.2 Central Command Module (CCM)
--------------------------------

The CCM is the guidance law executor and datalink hub. It runs the full 8-phase state machine, fuses inertial and barometric data from all three boards, commands fin and jetavane deflections to the ASAMs over UART, and fires pyrotechnic channels for staging and recovery.
-------------------------------------------------------------------------------------------------------------------------------------------------------------------------------------------------------------------------------------------------------------------------------

  ------------------- --------------------------------------------------------------------------------------
  **MCU**             RP2040 --- dual Cortex-M0+ @ 133MHz, 264KB SRAM, 16MB QSPI flash (telemetry log)
  **IMU**             ICM-42688-P --- SPI, 32kHz ODR (primary inertial reference)
  **Barometer**       BMP388 --- I2C, 200Hz (primary altitude reference)
  **Datalink**        Ebyte E22-900M22S --- SX1268, 915MHz ISM, 22dBm EIRP --- 915MHz quarter-wave antenna
  **Pyro channels**   3× IRFZ44N MOSFET --- CH1 nose chute · CH2 sustainer ignition relay · CH3 spare
  **Inter-board**     UART 115200 baud (commands) · SPI 4MHz (IMU data) · I2C 400kHz (baro) · JST-GH 8-pin
  **Arming**          Physical switch + software arm --- hardware interlock prevents accidental pyro fire
  ------------------- --------------------------------------------------------------------------------------

4.3 Auxiliary Sensor & Actuator Modules (ASAM-1 / ASAM-2)
---------------------------------------------------------
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

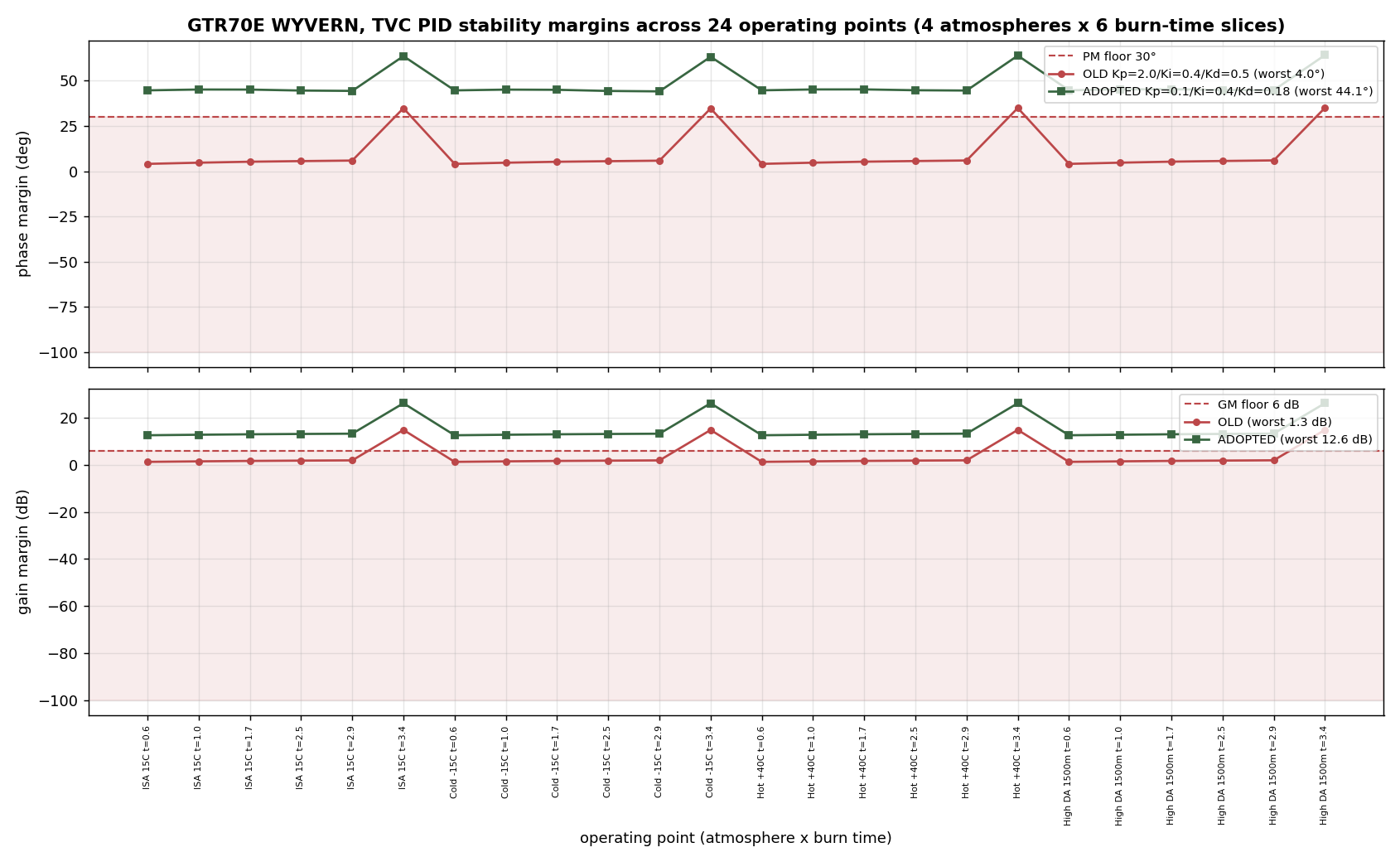
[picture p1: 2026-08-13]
Documentation/PID_TUNING_REPORT.png

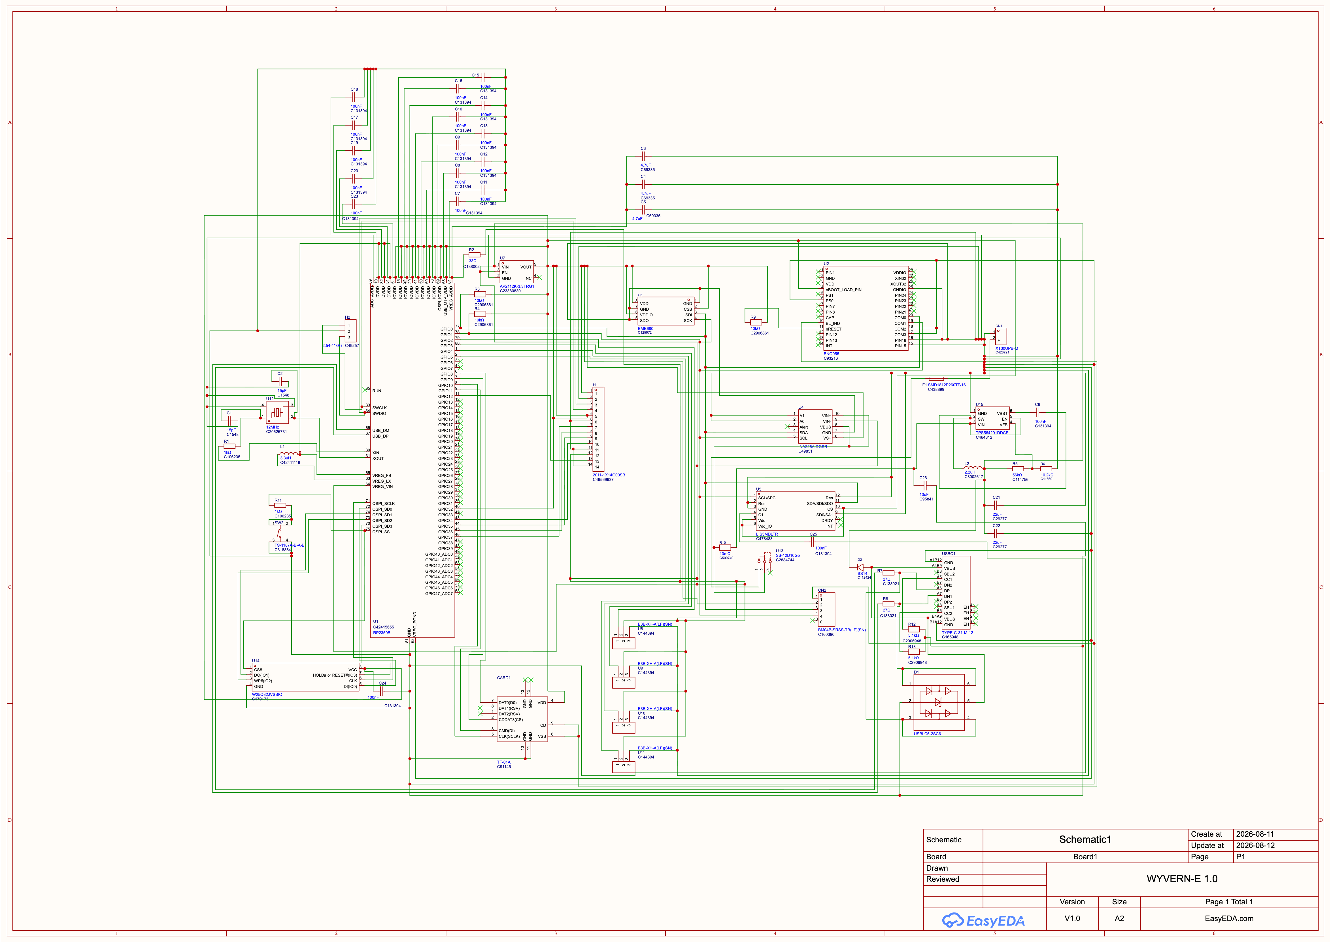
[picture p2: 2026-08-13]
PCB/SCH_Schematic1_1-P1_2026-08-12.png

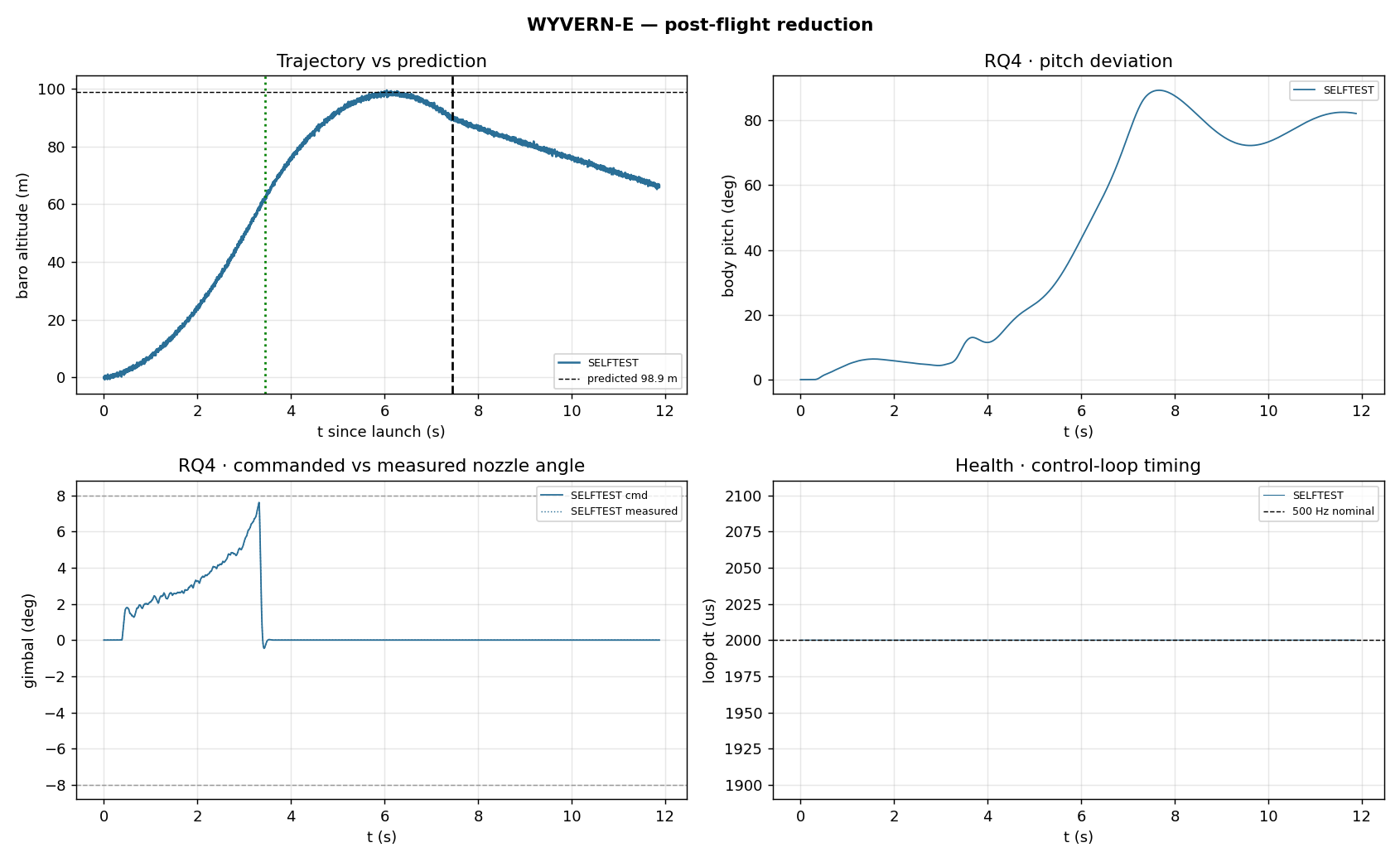
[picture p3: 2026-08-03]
Simulations/plots_flight/01_flight_overview.png

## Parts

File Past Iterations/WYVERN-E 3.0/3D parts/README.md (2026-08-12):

# 3D Parts — Rocket Airframe & Mechanism

Printable STL and CAD STEP for every rocket part of the two-stage 84 mm vehicle: nose, recovery bay, avionics bay, PCB mount, sustainer TVC bay (with the fin can), gimbal mechanism, interstage coupler, single fin test article, booster body, camera pod, outer shell, and the full assembly.

Per PDR-005 the fixed fins are on the sustainer (TVC bay), and the booster is finless.

## Regenerate

Parts are parametric. Edit `_generator/gen_rocket.py` (geometry in the `P` dict) and rebuild:

```
cd _generator
python3 gen_rocket.py     # requires OCP (cadquery-ocp); writes STL + STEP to the part folders
```

`_generator/wcad.py` is the thin OpenCascade helper layer. Material assignments and a mass report are printed at build time.

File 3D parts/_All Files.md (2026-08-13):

---
updated_at: 2026-08-11
---
# 3D parts, All Files

- [[Projects/Skylight/WYVERN/GTR70E WYVERN/WYVERN Project/3D parts/00_full_assembly.step]]
- [[Projects/Skylight/WYVERN/GTR70E WYVERN/WYVERN Project/3D parts/00_full_assembly.stl]]
- [[Projects/Skylight/WYVERN/GTR70E WYVERN/WYVERN Project/3D parts/01_nose_cone_ellipsoid_ASAAero.step]]
- [[Projects/Skylight/WYVERN/GTR70E WYVERN/WYVERN Project/3D parts/01_nose_cone_ellipsoid_ASAAero.stl]]
- [[Projects/Skylight/WYVERN/GTR70E WYVERN/WYVERN Project/3D parts/02_upper_bt_avionics_ASAAero.step]]
- [[Projects/Skylight/WYVERN/GTR70E WYVERN/WYVERN Project/3D parts/02_upper_bt_avionics_ASAAero.stl]]
- [[Projects/Skylight/WYVERN/GTR70E WYVERN/WYVERN Project/3D parts/03_lower_bt_chute_tvc_PETGCF.step]]
- [[Projects/Skylight/WYVERN/GTR70E WYVERN/WYVERN Project/3D parts/03_lower_bt_chute_tvc_PETGCF.stl]]
- [[Projects/Skylight/WYVERN/GTR70E WYVERN/WYVERN Project/3D parts/04_bulkhead_joint_PETGCF.step]]
- [[Projects/Skylight/WYVERN/GTR70E WYVERN/WYVERN Project/3D parts/04_bulkhead_joint_PETGCF.stl]]
- [[Projects/Skylight/WYVERN/GTR70E WYVERN/WYVERN Project/3D parts/05_motor_mount_29mm_PCFR.step]]
- [[Projects/Skylight/WYVERN/GTR70E WYVERN/WYVERN Project/3D parts/05_motor_mount_29mm_PCFR.stl]]
- [[Projects/Skylight/WYVERN/GTR70E WYVERN/WYVERN Project/3D parts/06_tvc_gimbal_2axis_PCFR.step]]
- [[Projects/Skylight/WYVERN/GTR70E WYVERN/WYVERN Project/3D parts/06_tvc_gimbal_2axis_PCFR.stl]]
- [[Projects/Skylight/WYVERN/GTR70E WYVERN/WYVERN Project/3D parts/07_fin_single_PETGCF.step]]
- [[Projects/Skylight/WYVERN/GTR70E WYVERN/WYVERN Project/3D parts/07_fin_single_PETGCF.stl]]
- [[Projects/Skylight/WYVERN/GTR70E WYVERN/WYVERN Project/3D parts/08_rail_button_1010_x2.step]]
- [[Projects/Skylight/WYVERN/GTR70E WYVERN/WYVERN Project/3D parts/08_rail_button_1010_x2.stl]]

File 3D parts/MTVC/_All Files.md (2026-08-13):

---
updated_at: 2026-08-02
---
# MTVC, All Files

*Auto-generated index, every file and subfolder linked for vault graph connectivity.*

---

## Files

- [[Projects/Skylight/WYVERN/GTR70E WYVERN/WYVERN Project/3D parts/MTVC/MTVC Assembly - Casing V2 WHITE.gcode.3mf]]
- [[Projects/Skylight/WYVERN/GTR70E WYVERN/WYVERN Project/3D parts/MTVC/MTVC Assembly - Casing V3.stl]]
- [[Projects/Skylight/WYVERN/GTR70E WYVERN/WYVERN Project/3D parts/MTVC/MTVC Assembly - Casing.gcode.3mf]]
- [[Projects/Skylight/WYVERN/GTR70E WYVERN/WYVERN Project/3D parts/MTVC/MTVC Assembly - Solenoid Frame V3.stl]]
- [[Projects/Skylight/WYVERN/GTR70E WYVERN/WYVERN Project/3D parts/MTVC/MTVC Assembly - Solenoid Frame V4.stl]]
- [[Projects/Skylight/WYVERN/GTR70E WYVERN/WYVERN Project/3D parts/MTVC/MTVC Assembly - Testing Stand V3.stl]]
- [[Projects/Skylight/WYVERN/GTR70E WYVERN/WYVERN Project/3D parts/MTVC/MTVC Assembly - Tube.gcode.3mf]]
- [[Projects/Skylight/WYVERN/GTR70E WYVERN/WYVERN Project/3D parts/MTVC/MTVC Assembly - Upper V3.stl]]
- [[Projects/Skylight/WYVERN/GTR70E WYVERN/WYVERN Project/3D parts/MTVC/MTVC Assembly V2 BLACK.gcode.3mf]]

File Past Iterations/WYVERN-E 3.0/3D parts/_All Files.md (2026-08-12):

---
updated_at: 2026-07-30
---
# 3D parts — All Files

*Auto-generated index — every file in this folder linked for vault graph connectivity (re-index pass, 2026-07-30).*

---

## Linked Items (auto-added)

- [[Projects/Skylight/WYVERN/Past Iterations/WYVERN-E 3.0/3D parts/00_full_assembly.step]]
- [[Projects/Skylight/WYVERN/Past Iterations/WYVERN-E 3.0/3D parts/00_full_assembly.stl]]
- [[Projects/Skylight/WYVERN/Past Iterations/WYVERN-E 3.0/3D parts/01_nose_cone.step]]
- [[Projects/Skylight/WYVERN/Past Iterations/WYVERN-E 3.0/3D parts/01_nose_cone.stl]]
- [[Projects/Skylight/WYVERN/Past Iterations/WYVERN-E 3.0/3D parts/02_recovery_bay.step]]
- [[Projects/Skylight/WYVERN/Past Iterations/WYVERN-E 3.0/3D parts/02_recovery_bay.stl]]
- [[Projects/Skylight/WYVERN/Past Iterations/WYVERN-E 3.0/3D parts/03_avionics_bay.step]]
- [[Projects/Skylight/WYVERN/Past Iterations/WYVERN-E 3.0/3D parts/03_avionics_bay.stl]]
- [[Projects/Skylight/WYVERN/Past Iterations/WYVERN-E 3.0/3D parts/04_fc_pi5_mount.step]]
- [[Projects/Skylight/WYVERN/Past Iterations/WYVERN-E 3.0/3D parts/04_fc_pi5_mount.stl]]
- [[Projects/Skylight/WYVERN/Past Iterations/WYVERN-E 3.0/3D parts/04_pcb_internal_mount.step]]
- [[Projects/Skylight/WYVERN/Past Iterations/WYVERN-E 3.0/3D parts/04_pcb_internal_mount.stl]]
- [[Projects/Skylight/WYVERN/Past Iterations/WYVERN-E 3.0/3D parts/04b_fc_tvc_bulkhead.step]]
- [[Projects/Skylight/WYVERN/Past Iterations/WYVERN-E 3.0/3D parts/04b_fc_tvc_bulkhead.stl]]
- [[Projects/Skylight/WYVERN/Past Iterations/WYVERN-E 3.0/3D parts/05_stage2_tvc_bay.step]]
- [[Projects/Skylight/WYVERN/Past Iterations/WYVERN-E 3.0/3D parts/05_stage2_tvc_bay.stl]]
- [[Projects/Skylight/WYVERN/Past Iterations/WYVERN-E 3.0/3D parts/06_tvc_gimbal_mech.step]]
- [[Projects/Skylight/WYVERN/Past Iterations/WYVERN-E 3.0/3D parts/06_tvc_gimbal_mech.stl]]
- [[Projects/Skylight/WYVERN/Past Iterations/WYVERN-E 3.0/3D parts/07_interstage_coupler.step]]
- [[Projects/Skylight/WYVERN/Past Iterations/WYVERN-E 3.0/3D parts/07_interstage_coupler.stl]]
- [[Projects/Skylight/WYVERN/Past Iterations/WYVERN-E 3.0/3D parts/08_fin_single.step]]
- [[Projects/Skylight/WYVERN/Past Iterations/WYVERN-E 3.0/3D parts/08_fin_single.stl]]
- [[Projects/Skylight/WYVERN/Past Iterations/WYVERN-E 3.0/3D parts/09_stage1_booster_body.step]]
- [[Projects/Skylight/WYVERN/Past Iterations/WYVERN-E 3.0/3D parts/09_stage1_booster_body.stl]]
- [[Projects/Skylight/WYVERN/Past Iterations/WYVERN-E 3.0/3D parts/10_camera_pod_fairing.step]]
- [[Projects/Skylight/WYVERN/Past Iterations/WYVERN-E 3.0/3D parts/10_camera_pod_fairing.stl]]
- [[Projects/Skylight/WYVERN/Past Iterations/WYVERN-E 3.0/3D parts/11_outer_shell_full.step]]
- [[Projects/Skylight/WYVERN/Past Iterations/WYVERN-E 3.0/3D parts/11_outer_shell_full.stl]]
- [[Projects/Skylight/WYVERN/Past Iterations/WYVERN-E 3.0/3D parts/README.md]]
- [[Projects/Skylight/WYVERN/Past Iterations/WYVERN-E 3.0/3D parts/_generator/_All Files.md]]

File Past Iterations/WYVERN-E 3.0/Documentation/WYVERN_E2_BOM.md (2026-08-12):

# WYVERN-E 2.0 — Bill of Materials

### A Skylight Rocketry Venture
##### 84 mm 2-Stage Magnetic-TVC 3D-Printed Research Vehicle
##### Companion to `WYVERN_E2_BOM.xlsx` (live formulas). Prices in USD; component-level costs are estimates where no public single-unit price exists. Electronics costs reconcile to the JLCPCB PCBA package (`PCB/.../WYVERN_E2_B{1,2}_BOM_PCBA.csv`).

## Avionics — Two-Board Stack (Board 1 TVC Actuator + Board 2 Main FC)

| Item | Part No. / Source | Qty | Unit ($) | Line ($) |
|---|---|---:|---:|---:|
| RP2350B flight MCU (sole processor) | Raspberry Pi QFN-80 (C42415655) | 1 | 1.20 | 1.20 |
| W25Q32JV QSPI boot flash | Winbond SOIC-8 (C82344) | 1 | 0.45 | 0.45 |
| SD-NAND data recorder (4 GB) | XTX XTSD04G LGA-8 (C558839) | 1 | 5.30 | 5.30 |
| microSD card socket (J7, edge push-pull) | Attend/Hanbo | 1 | 0.90 | 0.90 |
| ICM-42688-P 6-axis IMU | TDK (C1850418) | 1 | 6.50 | 6.50 |
| BME688 gas/T/RH (Main FC) | Bosch (C3664478) | 2 | 3.50 | 7.00 |
| BMP280 barometer (TVC board) | Bosch (C83291) | 1 | 2.00 | 2.00 |
| LIS3MDL magnetometer | ST (C478483) | 1 | 2.20 | 2.20 |
| BNO055 9-DOF (onboard, 1 per board) | Bosch LGA-28 (C93216) | 2 | 7.10 | 14.20 |
| INA219 bus current monitor (1 per board) | TI (C87469) | 2 | 1.80 | 3.60 |
| MAX713ESE+ NiCd fast-charge controller | ADI/Maxim SOIC-16 (narrow SO; *not* EPE/PDIP) | 1 | 4.50 | 4.50 |
| TPS54202 buck (3V3 & 5V, per board) | TI (C191884) | 4 | 0.70 | 2.80 |
| AO3400A N-FETs (3 solenoid + 3 pyro low-side) | AOS SOT-23 (C20917) | 7 | 0.10 | 0.70 |
| NTR4171P reverse-polarity P-FET (±20 V Vgs, 10S NiCd bus) | onsemi SOT-23 (C146715) | 1 | 0.11 | 0.11 |
| MMBT3906 PNP (NiCd charger pass transistor, B2 Q3) | onsemi SOT-23 (C2145) | 1 | 0.05 | 0.05 |
| SS34 freewheel/boost diode | SMA (C8678) | 4 | 0.12 | 0.48 |
| USBLC6 + SMF05C ESD arrays | ST/onsemi (C7519/C558425) | 3 | 0.10 | 0.30 |
| SMBJ16A TVS + PPTC fuse (per board front-end) | (C135050) | 4 | 0.20 | 0.80 |
| Arducam/OV parallel camera module + header | OV-series | 1 | 9.00 | 9.00 |
| USB-C 2.0 receptacle | GCT (C165948) | 1 | 0.60 | 0.60 |
| 12 MHz crystal (10 pF load) | 3225 4-pad (C518157) | 1 | 0.40 | 0.40 |
| 470 µF 25 V bulk cap (B1 C1, B2 C16) | radial | 2 | 0.30 | 0.60 |
| 100 µF 25 V bulk cap (B2 C24) | radial | 1 | 0.35 | 0.35 |
| 2512 shunts (0.01 Ω ×2 + 0.5 Ω ×1) | 1% | 3 | 0.22 | 0.66 |
| RBF pull-pin + headers / screw term / XT30 | assorted | 1 | 5.00 | 5.00 |
| Passives lot (0603 R/C, crystal caps, LED) | assorted | 1 | 4.00 | 4.00 |
| PCB fabrication — Board 1 (2-layer) + Board 2 (4-layer ENIG) | JLCPCB | 1 | 30.00 | 30.00 |
| **Subtotal** | | | | **103.70** |

*Cross-checked 2026-06-20 against the final `WYVERN_E2_B{1,2}_BOM_PCBA.csv` (post-gerber).
Corrections vs. the prior revision: BNO055 is mounted on **both** boards (B1 U1 + B2 U7), not
one — qty corrected 1→2. The radial-cap line was 3× 470 µF, but the final gerber places only
2× 470 µF (B1 C1, B2 C16) plus a separate 1× 100 µF (B2 C24) — split into two lines. The 2512
shunt count is 3 (0.01 Ω ×2 + 0.5 Ω ×1 across both boards), not 5. Added the MMBT3906 NiCd
charger pass transistor (B2 Q3), which was present in the final BOM but missing from the prior
revision. All other quantities (TPS54202 ×4, AO3400A ×7, SS34 ×4, SMBJ16A+PPTC ×4,
USBLC6+SMF05C ×3, INA219 ×2) were verified correct against the gerber BOM and left unchanged.*

## External Modules

| Item | Part No. / Source | Qty | Unit ($) | Line ($) |
|---|---|---:|---:|---:|
| BNO055 9-DOF breakout (gimbal-mounted) | [Adafruit 2472](https://www.adafruit.com/product/2472) | 1 | 34.95 | 34.95 |
| Piezo vibration sensor | film, analog → ADC | 1 | 1.50 | 1.50 |
| **Subtotal** | | | | **36.45** |

*(No external RRC3+ altimeter — dual-deploy and 2nd-stage ignition are handled onboard by the RP2350B pyro channels with hardware continuity + the RBF arm-gate. The camera is now an onboard module on the Main FC.)*

## Actuators & Power

| Item | Part No. / Source | Qty | Unit ($) | Line ($) |
|---|---|---:|---:|---:|
| 12 V mini electromagnet (TVC solenoid) | [TOMSHIELE](https://www.amazon.com/dp/B0CTG4X882) | 3 | 9.99 | 29.97 |
| 12 V 1300 mAh NiCd 10S1P pack | [Tenergy](https://power.tenergy.com) | 1 | 24.99 | 24.99 |
| **Subtotal** | | | | **54.96** |

## Propulsion (per flight)

| Item | Part No. / Source | Qty | Unit ($) | Line ($) |
|---|---|---:|---:|---:|
| AeroTech G78-4 Mojave Green 29 mm (booster) | [BuyRocketMotors](https://www.buyrocketmotors.com) | 1 | 31.19 | 31.19 |
| AeroTech F25-4 White Lightning 29 mm (sustainer) | [BuyRocketMotors](https://www.buyrocketmotors.com) | 1 | 27.00 | 27.00 |
| First Fire Jr starters (3-pack) | AeroTech | 1 | 9.99 | 9.99 |
| MJG Firewire Initiator (3 ft leads) | MJG | 2 | 3.50 | 7.00 |
| E-Match Mate bulkhead canister (2 pk) | Apogee | 1 | 7.95 | 7.95 |
| FFFFg black powder (per-flight lot) | — | 1 | 1.00 | 1.00 |
| **Subtotal** | | | | **84.13** |

*Motor pricing corrected 2026-06-20 to actual procurement prices (was a stale lower estimate):
G78-4 $31.19, F25-4 $27.00 — both confirmed against the Procurement Log.*

## Recovery

| Item | Part No. / Source | Qty | Unit ($) | Line ($) |
|---|---|---:|---:|---:|
| 18″ elliptical chute (booster, 6.0 m/s) | Apogee | 1 | 12.95 | 12.95 |
| 24″ elliptical chute (sustainer main, 7.5 m/s, carries avionics) | Apogee | 1 | 16.95 | 16.95 |
| 1/8″ tubular Kevlar shock cord | [BuyRocketMotors](https://www.buyrocketmotors.com) (6 ft) | 6 | 1.50 | 9.00 |
| **Subtotal** | | | | **38.90** |

## Airframe & Mechanism (filament, by mass)

RQ2 down-selects among PETG-CF / ASA / PLA Basic; the flight airframe ships in the best performer (PETG-CF primary basis below). Fins, TVC, and the test stand all ship in PC-FR — no plain (non-FR) PC is stocked, so PC-FR stands in across every high-heat/impact role.

| Item | Source | Qty (kg) | Unit ($/kg) | Line ($) |
|---|---|---:|---:|---:|
| PETG-CF (primary structure) | Bambu Labs, Procurement Log | 0.450 | 25.99 | 11.70 |
| PLA Basic (RQ2 candidate / fin test articles) | Bambu Labs, Procurement Log | 0.060 | 19.99 | 1.20 |
| ASA Aero (nose / fairings) | Bambu Labs, Procurement Log | 0.080 | 45.99 | 3.68 |
| PC-FR (fins) | Bambu Labs, Procurement Log | 0.070 | 43.99 | 3.08 |
| PC-FR (TVC + test stand) | Bambu Labs, Procurement Log | 0.250 | 43.99 | 11.00 |
| **Subtotal** | | | | **30.65** |

*Updated 2026-06-20 to actual per-kilogram spool prices from the Procurement Log (replacing
the prior $/kg estimates: PETG-CF was guessed at $40/kg, actual $25.99/kg; ASA was guessed at
$30/kg, actual $45.99/kg; PC-FR was guessed at $80/kg, actual $43.99/kg). The fins line was
also swapped from plain PC (never purchased, $50/kg estimate) to PC-FR at the actual $43.99/kg
spool price — no non-FR PC exists on the procurement tracker, so PC-FR now covers every
high-heat/impact role (fins, TVC, test stand) with real pricing instead of a guess.*

## Ground Support Equipment (one-time)

| Item | Source | Qty | Unit ($) | Line ($) |
|---|---|---:|---:|---:|
| Estes Pro Series II Launch Controller | Estes | 1 | 43.99 | 43.99 |
| Estes Pro Series II Launch Rail | Estes | 1 | 179.99 | 179.99 |
| Wishiot 10 kg load cell + HX711 | [Amazon](https://www.amazon.com/dp/B0CRCY863F) | 1 | 11.99 | 11.99 |
| Adafruit Metro M4 | Adafruit | 1 | 27.50 | 27.50 |
| microSD breakout | Adafruit/SparkFun | 1 | 7.50 | 7.50 |
| PLA filament (wind tunnel) | est | 800 | 0.020 | 16.00 |
| **Subtotal** | | | | **286.97** |

*Correction (2026-06-20): the launch controller and launch rail are billed separately by Estes
— the controller alone is $43.99; the rail is its own $179.99 line. The prior single
"rail + controller" line at $79.99 understated this category by $143.99.*

## Procurement Log (Actual Purchases — Skylight Rocketry Budget Tracker)

The engineering BOM above prices a *single flight stack* component-by-component. The table
below is the actual running procurement ledger (CSW Aerospace Budget tracker, reconciled
2026-06-19): bulk filament spools, spares, and one-time tooling bought across the build, not
divided per-unit. Two AeroTech motor line items appeared twice in the source tracker (status
updated from "On Hold" → "Requisitioned" as a new row instead of in place); they are
deduplicated to one line each here. **The PCB line below substitutes the estimated landed
PCBA cost (~$481 for 5 complete two-board stacks, `WYVERN_E2_JLCPCB_Cost_Analysis.md` §4/§6)
for the $600.00 figure in the source tracker**, since $600 was a placeholder/quoted figure
recorded before the JLCPCB cost model was built out.

| Type | Item | Qty | Unit ($) | Line ($) | Status |
|---|---|---:|---:|---:|---|
| 3D Printing | Bambu PETG-CF filament (1 kg) | 2 | 25.99 | 51.98 | Acquired |
| 3D Printing | Bambu PLA Basic filament (1 kg) | 3 | 19.99 | 59.97 | Acquired |
| 3D Printing | Bambu ASA Aero filament w/ spool (1 kg) | 3 | 45.99 | 137.97 | Requisitioned |
| 3D Printing | Bambu PC-FR filament w/ spool (1 kg) | 4 | 43.99 | 175.96 | Requisitioned |
| Rocketry | Estes Pro Series II launch controller | 1 | 43.99 | 43.99 | Aero Budget |
| Rocketry | Estes Pro Series II launch rail *(separate line from controller — added 2026-06-20)* | 1 | 179.99 | 179.99 | Aero Budget |
| Rocketry | AeroTech F25-4 motor (29 mm) | 3 | 27.00 | 81.00 | Requisitioned |
| Rocketry | AeroTech G78-4 motor (29 mm) | 3 | 31.19 | 93.57 | Requisitioned |
| Rocketry | 24″ rip-stop nylon parachute | 6 | 10.25 | 61.50 | Requisitioned |
| Electronics | Jolly Logic Altimeter 2 | 1 | 79.95 | 79.95 | Aero Budget |
| Electronics | 24 AWG flexible silicone wire | 1 | 15.99 | 15.99 | Aero Budget |
| Electronics | Arduino Nano V3 ATmega328P (3-pack) | 1 | 15.99 | 15.99 | Aero Budget |
| Electronics | Adafruit BNO085 9-DOF IMU breakout | 2 | 24.99 | 49.98 | Aero Budget |
| Electronics | STEMMA QT/Qwiic cable, female | 3 | 0.95 | 2.85 | Aero Budget |
| Electronics | STEMMA QT/Qwiic cable, male | 3 | 0.95 | 2.85 | Aero Budget |
| Electronics | Tenergy 12 V 1300 mAh NiCd pack (10S1P) | 4 | 71.99 | 287.96 | Requisitioned |
| Electronics | 50 N 12 V micro lifting solenoid | 3 | 10.99 | 32.97 | Order In-Progress |
| Electronics | Breadboard jumper wire kit | 1 | 14.99 | 14.99 | Order In-Progress |
| Electronics | N52 rare-earth magnets (20 ct) | 1 | 25.00 | 25.00 | Order In-Progress |
| Electronics | IRF520 MOSFET driver (4 ct) | 1 | 6.99 | 6.99 | Order In-Progress |
| Electronics | 1N4007 rectifier diode (125 ct) | 1 | 5.99 | 5.99 | Order In-Progress |
| Electronics | 12 V 2 A power supply adapter | 1 | 11.99 | 11.99 | Order In-Progress |
| Electronics | 5-pack IDC 2×10 20P female connector | 1 | 9.75 | 9.75 | Requisitioned |
| Electronics | **WYVERN-E custom PCBs (2 boards, 5 of each) — *estimated landed PCBA, not the $600 placeholder*** | 1 | **481.00** | **481.00** | Requisitioned (est.) |
| Hand Tools | Kapton high-temp tape | 1 | 9.99 | 9.99 | Aero Budget |
| Hand Tools | J-B Weld twin-tube epoxy | 1 | 21.39 | 21.39 | Order In-Progress |
| Hand Tools | Super Lube PTFE grease | 1 | 10.99 | 10.99 | Order In-Progress |
| **TOTAL (27 deduplicated line items + launch rail, PCB at estimate)** | | | | **1,972.55** | |

*Source tracker total (59 rows incl. the 2 duplicate motor-status rows, $600 PCB placeholder):
$2,086.13. With duplicates removed and the PCB line at the $481 JLCPCB estimate: $1,792.56 —
a $293.57 reduction (duplicate motor rows: $174.57; PCB placeholder→estimate: $119.00). The
Estes launch rail ($179.99) was billed as its own line separate from the launch controller and
is added on top of the source-tracker reconciliation, bringing the corrected total to
**$1,972.55**. (No radio/telemetry module: the rocket carries no downlink — all flight data is logged onboard and retrieved post-flight.)*

## Totals

| Category | Subtotal ($) |
|---|---:|
| Avionics — two-board stack | 103.70 |
| External Modules | 36.45 |
| Actuators & Power | 54.96 |
| Propulsion (per flight) | 84.13 |
| Recovery | 38.90 |
| Airframe & Mechanism (filament) | 30.65 |
| Ground Support Equipment (one-time) | 286.97 |
| **GRAND TOTAL (per-unit engineering BOM)** | **635.76** |
| **Actual procurement to date (dedup. + launch rail, PCB at JLCPCB estimate)** | **1,972.55** |

*The two totals answer different questions: the per-unit engineering BOM (§1–7) prices what
one flight-ready stack costs to build from scratch at unit prices; the procurement log prices
what has actually been bought — bulk filament spools, 4× battery packs, 6× spares motors/chutes,
one-time GSE and tooling — which naturally runs higher since it covers spares and multiple
build cycles, not one stack.*

*Per-flight consumables* (propulsion: motors, igniters, BP) ≈ **$84.13**; the chutes and
shock cord are reusable. The remainder is non-recurring (PCBs, modules, GSE) or reusable
(airframe). The electronics subtotal rose ~$30 vs the
single-board intermediate rev: the architecture split into a 2-layer TVC Actuator + a 4-layer
Main FC, and the onboard camera, SD-NAND recorder, and MAX713 charger were added — while the
external $70 RRC3+ altimeter was eliminated by moving dual-deploy onboard. Estimated unit costs
are used where a single-unit public price is unavailable; update against quotes in the `.xlsx`
(formulas recompute automatically; regenerate it from this table to stay in sync).

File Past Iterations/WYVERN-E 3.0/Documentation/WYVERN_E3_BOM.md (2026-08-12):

# WYVERN-E 3.0 — Bill of Materials

### A Skylight Rocketry Venture
##### 84 mm two-stage Raspberry Pi 5 TVC research vehicle · off-the-shelf, no custom PCBs
##### Two TVC systems built for A/B comparison (solenoid vs servo); 3 flights each + ground tests.

> **The fully costed, live-linked, in-stock version of this BOM is `WYVERN_E3_BOM.xlsx`** (verified
> June 2026; every line has a working purchase link + stock status). Grand total **$1,505.63**.
> This Markdown copy is the human-readable summary; the spreadsheet is canonical for prices/links.
## 1. Flight Computer (off-the-shelf)

| Item | Source | Qty | Unit ($) | Line ($) |
|---|---|---:|---:|---:|
| Raspberry Pi 5 (4 GB) | Raspberry Pi | 1 | 60.00 | 60.00 |
| Active cooler (heatsink + fan) | Raspberry Pi | 1 | 5.00 | 5.00 |
| Camera Module 3 (wide, NoIR optional) | Raspberry Pi | 1 | 25.00 | 25.00 |
| BNO085 9-DOF (TVC gimbal-mounted) | Adafruit 4754 | 1 | 24.95 | 24.95 |
| BNO085 9-DOF (central FC module) | Adafruit 4754 | 1 | 24.95 | 24.95 |
| BNO085 9-DOF (nose cone) | Adafruit 4754 | 1 | 24.95 | 24.95 |
| LSM6DSO32 6-axis IMU (±32 g accel + gyro) | Adafruit 4692 | 1 | 11.95 | 11.95 |
| LIS2MDL 3-axis magnetometer | Adafruit 4488 | 1 | 4.95 | 4.95 |
| BMP280 barometer | Adafruit 2651 | 1 | 9.95 | 9.95 |
| BME688 gas/T/P/RH (VOC) | Adafruit 5046 | 1 | 22.50 | 22.50 |
| microSD breakout (SPI) + 32 GB card — video | Adafruit 4682 + card | 1 | 12.95 | 12.95 |
| microSD breakout (SPI) + 32 GB card — flight log | Adafruit 4682 + card | 1 | 12.95 | 12.95 |
| TCA9548A I²C multiplexer (3× BNO085 same-addr) | Adafruit 2717 | 1 | 6.95 | 6.95 |
| Pull-pin arming jumper + keyed connector | assorted | 1 | 5.00 | 5.00 |
| GPIO breakout/proto HAT + harness | assorted | 1 | 18.00 | 18.00 |
| **Subtotal** | | | | **270.05** |
## 2. Power System (USB-C rechargeable)

Sized for 5 flights + 2 h+ idle (≈ 24 Wh w/ margin → 33 Wh pack, 1.9× margin). 11.1 V feeds
solenoids directly; bucks supply 5 V/5 A (Pi 5) and 6 V (servos). See *Power_Mass_Motor* §1.

| Item | Source | Qty | Unit ($) | Line ($) |
|---|---|---:|---:|---:|
| 3S Li-ion pack, 11.1 V 3000 mAh (33 Wh) | 18650 ×3 | 1 | 30.00 | 30.00 |
| 3S BMS + USB-C PD charge board (12.6 V) | IP2368-class | 1 | 16.00 | 16.00 |
| 5 V / 5 A buck (Raspberry Pi 5 rail) | module | 1 | 10.00 | 10.00 |
| 6 V / 5 A buck/UBEC (servo rail) | module | 1 | 8.00 | 8.00 |
| Power switch + distribution + fuse | assorted | 1 | 8.00 | 8.00 |
| **Subtotal** | | | | **72.00** |
## 3. Recovery & Pyro

| Item | Source | Qty | Unit ($) | Line ($) |
|---|---|---:|---:|---:|
| RRC3+ dual-deploy altimeter (apogee → drogue/main) | MissileWorks | 1 | 79.95 | 79.95 |
| 24″ elliptical main chute | Apogee | 1 | 16.95 | 16.95 |
| 1/8″ tubular Kevlar shock cord (8 ft) | BuyRocketMotors | 8 | 1.50 | 12.00 |
| MJG Firewire initiators (recovery charges) | MJG | 4 | 3.50 | 14.00 |
| E-Match Mate bulkhead canister | Apogee | 1 | 7.95 | 7.95 |
| FFFFg black powder (per-flight lot) | — | 1 | 4.00 | 4.00 |
| **Subtotal** | | | | **134.85** |
## 4. TVC — Solenoid System (A)

| Item | Source | Qty | Unit ($) | Line ($) |
|---|---|---:|---:|---:|
| 12 V mini pull-solenoid (TVC actuator) | TOMSHIELE | 3 | 9.99 | 29.97 |
| 3-channel low-side MOSFET driver board (logic-level, PWM) | generic | 1 | 12.00 | 12.00 |
| SS34 freewheel diodes + 0.02 Ω shunts (current sense) | assorted | 1 | 6.00 | 6.00 |
| Gimbal mechanism (PC-FR cradle, pivots, return springs) | printed + hw | 1 | 22.00 | 22.00 |
| **Subtotal** | | | | **69.97** |
## 5. TVC — Servo System (B, BPS-style, up-rated)

Sized for the G64W: gimbal-axis torque ≈ 0.63 N·m at ±5°/100 N peak → **~16 kg·cm** required
(SF 2.5); BPS's 9 g micro servos (~2 kg·cm, for ~10 N motors) are ~8× too weak, so high-torque
digital metal-gear servos are used. See *Power_Mass_Motor* §3 + *TVC_Comparison*.

| Item | Source | Qty | Unit ($) | Line ($) |
|---|---|---:|---:|---:|
| High-torque digital servo (~35 kg·cm, metal gear, DS3235) | ANNIMOS | 3 | 18.99 | 56.97 |
| PCA9685 16-ch PWM servo driver (I²C) | Adafruit 815 | 1 | 8.95 | 8.95 |
| Servo gimbal linkage + ball-links + mount (PC-FR) | printed + hw | 1 | 25.00 | 25.00 |
| **Subtotal** | | | | **90.92** |
## 6. Propulsion (motors — A/B test plan)

3 flights × 2 TVC methods = **6 flights** (each = 1 booster + 1 sustainer); **2 ground static
fires per motor type**; plus the RQ3 jetvane erosion campaign on E-class motors.

| Item | Source | Qty | Unit ($) | Line ($) |
|---|---|---:|---:|---:|
| **AeroTech G25W-10A** sustainer reload (#072510) — 6 flights + 2 ground | AeroTech | 8 | 30.99 | 247.92 |
| **AeroTech F40-7W** booster reload (#64007) — 6 flights + 2 ground | AeroTech | 8 | 14.99 | 119.92 |
| **RMS-29/40-120 hardware set** (#91291) — covers *both* stages; ×2 (one per stage, flown together) | AeroTech | 2 | 86.99 | 173.98 |
| First Fire Jr igniters (3-pk; spares/2nd-stage — reloads ship with their own) | AeroTech | 2 | 9.99 | 19.98 |
| E-class motors — jetvane erosion test (RQ3) | Estes E12-0 | 6 | 10.00 | 60.00 |
| **Subtotal** | | | | **621.80** |
## 7. Airframe & Mechanism (filament, by mass)

RQ2 down-selects among PETG-CF / ASA / PLA Basic; PC-FR for fins + TVC + bulkhead (heat/flame).

| Item | Source | Qty (kg) | Unit ($/kg) | Line ($) |
|---|---|---:|---:|---:|
| PETG-CF (primary structure + FC bay) | Bambu Labs | 0.380 | 25.99 | 9.88 |
| ASA Aero (nose / fairings) | Bambu Labs | 0.080 | 45.99 | 3.68 |
| PC-FR (fins + TVC bay + bulkhead) | Bambu Labs | 0.280 | 43.99 | 12.32 |
| PLA Basic (RQ2 fin test articles) | Bambu Labs | 0.060 | 19.99 | 1.20 |
| **Subtotal** | | | | **27.08** |
## 8. Ground Support Equipment (one-time)

| Item | Source | Qty | Unit ($) | Line ($) |
|---|---|---:|---:|---:|
| Static stand 20 kg load cell + HX711 (G64W peak ~100 N > old 10 kg cell) | Amazon | 1 | 14.99 | 14.99 |
| Adafruit Metro M4 + microSD (stand DAQ) | Adafruit | 1 | 35.00 | 35.00 |
| Servo TVC ground test rig (bench gimbal + dummy load) | printed + hw | 1 | 25.00 | 25.00 |
| Estes Pro Series II launch rail + controller | Estes | 1 | 124.00 | 124.00 |
| PLA filament (wind tunnel) | est | 0.800 | 19.99 | 15.99 |
| **Subtotal** | | | | **214.97** |
## 9. Totals

| Category | Subtotal ($) |
|---|---:|
| 1. Flight Computer | 270.05 |
| 2. Power System | 72.00 |
| 3. Recovery & Pyro | 134.85 |
| 4. TVC — Solenoid System (A) | 69.97 |
| 5. TVC — Servo System (B) | 90.92 |
| 6. Propulsion (6 flights × booster+sustainer + 2 ground each + erosion) | 621.80 |
| 7. Airframe (filament) | 27.08 |
| 8. Ground Support Equipment (one-time) | 214.97 |
| **GRAND TOTAL** | **1,505.63** |

*Per-flight consumables* (F40-7W booster + G25W-10A sustainer reloads + spare igniter + BP ≈ $46/flight;
the single RMS-29/40-120 case family covers both stages — 2 sets so a 2-stage flight has one case per
stage — and is fully reusable). AeroTech reloads ship with their own igniter.
The flight computer, both TVC systems, power pack, RRC3+, casings, and GSE are non-recurring or
reusable. Both TVC systems are built once and swapped between the 6 flights (3 each).

> *No custom PCBs, no LoRa/radio (data logged onboard to dual microSD, retrieved post-flight),
> two-stage but no FAA waiver / no Level-1 cert: liftoff ≈ 1.29–1.39 kg < 1500 g, total
> propellant ≈ 78 g < 125 g, both motors ≤ G class.*

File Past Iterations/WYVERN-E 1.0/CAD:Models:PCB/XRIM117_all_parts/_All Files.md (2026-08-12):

---
updated_at: 2026-05-27
---
# XRIM117_all_parts — All Files

*Complete index of all files in `Projects/WYVERN-E/CAD:Models:PCB/XRIM117_all_parts/`. Auto-generated — every file [[wikilinked]] for Obsidian graph connectivity.*

---

**Total files: 19**

## STL Files (19)

- [[01_nose_cone.stl]]
- [[02_bt1_chute_bay.stl]]
- [[03_bt2_mid_section.stl]]
- [[04_bt3_aft_section.stl]]
- [[05_bt4_booster_bay.stl]]
- [[06_fin_ring1_aft.stl]]
- [[07_fin_ring2_mid.stl]]
- [[08_motor_tube_38mm.stl]]
- [[09_motor_tube_29mm.stl]]
- [[10_cr_bt3_fwd.stl]]
- [[11_cr_bt3_mid.stl]]
- [[12_cr_bt3_aft.stl]]
- [[13_cr_bt4_fwd.stl]]
- [[14_cr_bt4_aft.stl]]
- [[15_tvc_outer_ring.stl]]
- [[16_tvc_inner_cradle.stl]]
- [[17_pcb_ccm.stl]]
- [[18_pcb_asam1.stl]]
- [[19_pcb_asam2.stl]]

## Linked Items (auto-added)

- [[Projects/Skylight/WYVERN/Past Iterations/WYVERN-E 1.0/CAD:Models:PCB/XRIM117_all_parts/01_nose_cone.stl]]
- [[Projects/Skylight/WYVERN/Past Iterations/WYVERN-E 1.0/CAD:Models:PCB/XRIM117_all_parts/02_bt1_chute_bay.stl]]
- [[Projects/Skylight/WYVERN/Past Iterations/WYVERN-E 1.0/CAD:Models:PCB/XRIM117_all_parts/03_bt2_mid_section.stl]]
- [[Projects/Skylight/WYVERN/Past Iterations/WYVERN-E 1.0/CAD:Models:PCB/XRIM117_all_parts/04_bt3_aft_section.stl]]
- [[Projects/Skylight/WYVERN/Past Iterations/WYVERN-E 1.0/CAD:Models:PCB/XRIM117_all_parts/05_bt4_booster_bay.stl]]
- [[Projects/Skylight/WYVERN/Past Iterations/WYVERN-E 1.0/CAD:Models:PCB/XRIM117_all_parts/06_fin_ring1_aft.stl]]
- [[Projects/Skylight/WYVERN/Past Iterations/WYVERN-E 1.0/CAD:Models:PCB/XRIM117_all_parts/07_fin_ring2_mid.stl]]
- [[Projects/Skylight/WYVERN/Past Iterations/WYVERN-E 1.0/CAD:Models:PCB/XRIM117_all_parts/08_motor_tube_38mm.stl]]
- [[Projects/Skylight/WYVERN/Past Iterations/WYVERN-E 1.0/CAD:Models:PCB/XRIM117_all_parts/09_motor_tube_29mm.stl]]
- [[Projects/Skylight/WYVERN/Past Iterations/WYVERN-E 1.0/CAD:Models:PCB/XRIM117_all_parts/10_cr_bt3_fwd.stl]]
- [[Projects/Skylight/WYVERN/Past Iterations/WYVERN-E 1.0/CAD:Models:PCB/XRIM117_all_parts/11_cr_bt3_mid.stl]]
- [[Projects/Skylight/WYVERN/Past Iterations/WYVERN-E 1.0/CAD:Models:PCB/XRIM117_all_parts/12_cr_bt3_aft.stl]]
- [[Projects/Skylight/WYVERN/Past Iterations/WYVERN-E 1.0/CAD:Models:PCB/XRIM117_all_parts/13_cr_bt4_fwd.stl]]
- [[Projects/Skylight/WYVERN/Past Iterations/WYVERN-E 1.0/CAD:Models:PCB/XRIM117_all_parts/14_cr_bt4_aft.stl]]
- [[Projects/Skylight/WYVERN/Past Iterations/WYVERN-E 1.0/CAD:Models:PCB/XRIM117_all_parts/15_tvc_outer_ring.stl]]
- [[Projects/Skylight/WYVERN/Past Iterations/WYVERN-E 1.0/CAD:Models:PCB/XRIM117_all_parts/16_tvc_inner_cradle.stl]]
- [[Projects/Skylight/WYVERN/Past Iterations/WYVERN-E 1.0/CAD:Models:PCB/XRIM117_all_parts/17_pcb_ccm.stl]]
- [[Projects/Skylight/WYVERN/Past Iterations/WYVERN-E 1.0/CAD:Models:PCB/XRIM117_all_parts/18_pcb_asam1.stl]]
- [[Projects/Skylight/WYVERN/Past Iterations/WYVERN-E 1.0/CAD:Models:PCB/XRIM117_all_parts/19_pcb_asam2.stl]]
- [[Projects/Skylight/WYVERN/Past Iterations/WYVERN-E 1.0/CAD:Models:PCB/XRIM117_all_parts/_All Files.md]]
- [[Projects/Skylight/WYVERN/Past Iterations/WYVERN-E 1.0/CAD:Models:PCB/XRIM117_all_parts/_RevC_RETIRED_FINS.md]]

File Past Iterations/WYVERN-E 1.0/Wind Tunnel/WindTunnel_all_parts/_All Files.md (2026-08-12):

---
updated_at: 2026-05-27
---
# WindTunnel_all_parts — All Files

*Complete index of all files in `Projects/WYVERN-E/Wind Tunnel/WindTunnel_all_parts/`. Auto-generated — every file [[wikilinked]] for Obsidian graph connectivity.*

---

**Total files: 23**

## Text Files (1)

- [[README.txt]]

## STL Files (22)

- [[01_bellmouth_inlet_120mm.stl]]
- [[02_settling_chamber_150mm.stl]]
- [[03_honeycomb_frame_50mm.stl]]
- [[04_screen_frame_40mm.stl]]
- [[05_smoke_strut_section_100mm.stl]]
- [[06A_contraction_cone_seg1_z0-150mm.stl]]
- [[06B_contraction_cone_seg2_z150-300mm.stl]]
- [[06C_contraction_cone_seg3_z300-450mm.stl]]
- [[06D_contraction_cone_seg4_z450-600mm.stl]]
- [[06E_contraction_cone_seg5_z600-750mm.stl]]
- [[06F_contraction_cone_seg6_z750-900mm.stl]]
- [[07A_test_section_167mm.stl]]
- [[07B_test_section_167mm.stl]]
- [[07C_test_section_166mm.stl]]
- [[08_diffuser_sq_to_circle_220mm.stl]]
- [[09_fan_housing_200mm_dia.stl]]
- [[10_fan_assembly_7blade.stl]]
- [[11_junction_ring_large_156sq_30mm.stl]]
- [[12_junction_ring_small_156sq_20mm.stl]]
- [[13_sting_mount_aoa_bracket.stl]]
- [[14_fin_module_clamp_half.stl]]
- [[WYVERN_WindTunnel_FullAssembly.stl]]

## Linked Items (auto-added)

- [[Projects/Skylight/WYVERN/Past Iterations/WYVERN-E 1.0/Wind Tunnel/WindTunnel_all_parts/01_bellmouth_inlet_120mm.stl]]
- [[Projects/Skylight/WYVERN/Past Iterations/WYVERN-E 1.0/Wind Tunnel/WindTunnel_all_parts/02_settling_chamber_150mm.stl]]
- [[Projects/Skylight/WYVERN/Past Iterations/WYVERN-E 1.0/Wind Tunnel/WindTunnel_all_parts/03_honeycomb_frame_50mm.stl]]
- [[Projects/Skylight/WYVERN/Past Iterations/WYVERN-E 1.0/Wind Tunnel/WindTunnel_all_parts/04_screen_frame_40mm.stl]]
- [[Projects/Skylight/WYVERN/Past Iterations/WYVERN-E 1.0/Wind Tunnel/WindTunnel_all_parts/05_smoke_strut_section_100mm.stl]]
- [[Projects/Skylight/WYVERN/Past Iterations/WYVERN-E 1.0/Wind Tunnel/WindTunnel_all_parts/06A_contraction_cone_seg1_z0-150mm.stl]]
- [[Projects/Skylight/WYVERN/Past Iterations/WYVERN-E 1.0/Wind Tunnel/WindTunnel_all_parts/06B_contraction_cone_seg2_z150-300mm.stl]]
- [[Projects/Skylight/WYVERN/Past Iterations/WYVERN-E 1.0/Wind Tunnel/WindTunnel_all_parts/06C_contraction_cone_seg3_z300-450mm.stl]]
- [[Projects/Skylight/WYVERN/Past Iterations/WYVERN-E 1.0/Wind Tunnel/WindTunnel_all_parts/06D_contraction_cone_seg4_z450-600mm.stl]]
- [[Projects/Skylight/WYVERN/Past Iterations/WYVERN-E 1.0/Wind Tunnel/WindTunnel_all_parts/06E_contraction_cone_seg5_z600-750mm.stl]]
- [[Projects/Skylight/WYVERN/Past Iterations/WYVERN-E 1.0/Wind Tunnel/WindTunnel_all_parts/06F_contraction_cone_seg6_z750-900mm.stl]]
- [[Projects/Skylight/WYVERN/Past Iterations/WYVERN-E 1.0/Wind Tunnel/WindTunnel_all_parts/07A_test_section_167mm.stl]]
- [[Projects/Skylight/WYVERN/Past Iterations/WYVERN-E 1.0/Wind Tunnel/WindTunnel_all_parts/07B_test_section_167mm.stl]]
- [[Projects/Skylight/WYVERN/Past Iterations/WYVERN-E 1.0/Wind Tunnel/WindTunnel_all_parts/07C_test_section_166mm.stl]]
- [[Projects/Skylight/WYVERN/Past Iterations/WYVERN-E 1.0/Wind Tunnel/WindTunnel_all_parts/08_diffuser_sq_to_circle_220mm.stl]]
- [[Projects/Skylight/WYVERN/Past Iterations/WYVERN-E 1.0/Wind Tunnel/WindTunnel_all_parts/09_fan_housing_200mm_dia.stl]]
- [[Projects/Skylight/WYVERN/Past Iterations/WYVERN-E 1.0/Wind Tunnel/WindTunnel_all_parts/10_fan_assembly_7blade.stl]]
- [[Projects/Skylight/WYVERN/Past Iterations/WYVERN-E 1.0/Wind Tunnel/WindTunnel_all_parts/11_junction_ring_large_156sq_30mm.stl]]
- [[Projects/Skylight/WYVERN/Past Iterations/WYVERN-E 1.0/Wind Tunnel/WindTunnel_all_parts/12_junction_ring_small_156sq_20mm.stl]]
- [[Projects/Skylight/WYVERN/Past Iterations/WYVERN-E 1.0/Wind Tunnel/WindTunnel_all_parts/13_sting_mount_aoa_bracket.stl]]
- [[Projects/Skylight/WYVERN/Past Iterations/WYVERN-E 1.0/Wind Tunnel/WindTunnel_all_parts/14_fin_module_clamp_half.stl]]
- [[Projects/Skylight/WYVERN/Past Iterations/WYVERN-E 1.0/Wind Tunnel/WindTunnel_all_parts/README.txt]]
- [[Projects/Skylight/WYVERN/Past Iterations/WYVERN-E 1.0/Wind Tunnel/WindTunnel_all_parts/WYVERN_WindTunnel_FullAssembly.stl]]
- [[Projects/Skylight/WYVERN/Past Iterations/WYVERN-E 1.0/Wind Tunnel/WindTunnel_all_parts/_All Files.md]]
- [[Projects/Skylight/WYVERN/Past Iterations/WYVERN-E 1.0/Wind Tunnel/WindTunnel_all_parts/_All Files.md.edtz]]

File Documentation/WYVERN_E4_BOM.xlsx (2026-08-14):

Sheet: BOM
GTR70E WYVERN - Master Bill of Materials
Reconciled 2026-08-14 against the live Amazon cart (25 items, $593.92 list / $582.37 after coupons) and the live Adafruit cart ($216.95). Pico 2 W perfboard revision; custom PCB1 fab retired. ABS dropped from RQ2 and from procurement. Three-point-bend rig cancelled, 20 kg load cell dropped. Lines reading NOT IN EITHER CART are zeroed from the to-buy total but are still required hardware.
1. Flight Computer & Sensors
Item | Storefront | Part # / Spec | Link | Note | Qty | Unit ($) | Line ($)
Raspberry Pi Pico 2 W (pre-soldered header) - flight FC + ground-stand FC | Adafruit | PID 6087 | Buy (https://www.amazon.com/gp/product/B0DP54FWX1) | 2026-08-13: RE-SOURCED from Amazon B0DP54FWX1 ($16.31) to Adafruit PID 6087 ($7.00 ea); qty2 in the live Adafruit cart. Two boards = flight FC + ground TVC stand FC, both running the same image (stand built with -DWYVERN_GROUND_TEST=1). | 2 | $7.00
BNO085 9-DOF IMU x4 (bay 0x4B, flight gimbal 0x4A, ground rig, spare) | Adafruit | PID 4754 | Buy (https://www.adafruit.com/product/4754) | FOUR units, confirmed 2026-08-14: (1) electronics bay 0x4B, DI->3V3; (2) flight TVC gimbal 0x4A, default; (3) ground servo test rig gimbal, so the flight unit never has to be un/re-mounted between bench and vehicle; (4) spare. The flight gimbal unit crosses the separation joint on pull-apart leads and is the most damage-exposed sensor on the vehicle. | 4 | $29.50
BMP388 precision barometric pressure/altitude sensor | Adafruit | PID 3966 | Buy (https://www.adafruit.com/product/3966) | 2026-08-13: qty1 in the live Adafruit cart at $9.95 (previously zeroed). PRIMARY altimeter at 0x77, SDO unconnected. BME688 (Already Acquired) is redundant pressure + environmental at 0x76. Row 80 is the zeroed duplicate. NOTE: baro.h / wyvern_config.h still treat BME688 as primary - firmware needs to swap to match the proposal. | 1 | $9.95
i3 4K Thumb Action Camera (64G card, self-contained ~36 g) | Amazon | i3 B0G4PD79FL (32G variant) | Buy (https://www.amazon.com/gp/product/B0DDSH1W1N) | in cart (32G variant, i3 B0G4PD79FL) | 1 | $67.99
USB-A/USB-C 3.0 OTG adapter set - NOT NEEDED | Amazon | B0FQBPZPKF | Buy (https://www.amazon.com/gp/product/B0FQBPZPKF) | DROPPED 2026-08-14, confirmed not needed. The USB-C microSD card reader in Already Acquired covers both the flight log and the i3 camera card. | 0 | $0.00
Subtotal
2. Power (2S LiPo + UBEC)
Item | Storefront | Part # / Spec | Link | Note | Qty | Unit ($) | Line ($)
OVONIC 2S 7.6 V 450 mAh 100C LiPo, XT30 (2-pack) - flight pack + spare | Amazon | B0D3F5SQ5T | Buy (https://www.amazon.com/dp/B0DGQ5HHMY) | 2026-08-13: $20.37 list, $10.18 after coupon. Two packs per order = flight + spare. 100C on 450 mAh is 45 A burst against the ~1.9 A the servos + UBEC actually pull. XT30 feeds PPTC -> arming switch -> UBEC. | 1 | $10.18
Hobbywing 5 V 3 A switching UBEC (NOT linear) | Amazon | Hobbywing B008ZNWOYY | Buy (https://www.amazon.com/dp/B008ZNWOYY) | *** FLIGHT-BLOCKING GAP: NOT IN EITHER CART (2026-08-13). *** PCB1 is retired, so there is no onboard buck - the Pico VSYS and the servo rail have nothing to run from without this. Order first. Must be 5 V 3 A SWITCHING; a linear BEC dissipating 2S down to 5 V at 1.9 A will cook. | 1 | $0.00
HTRC B3 2S-3S LiPo balance charger | Amazon | SSUPCHG B0FPDJP4GK | Buy (https://www.amazon.com/dp/B08HN5DZ5Y) | in cart; replaces HTRC B3 (superseded) | 1 | $15.63
Bulk cap 470 uF 10 V + 100 nF ceramic (ON HAND - see Already Acquired) | Amazon | low-ESR cap + SS34 | Buy (https://www.amazon.com/s?k=1000uF+low+ESR+capacitor+SS34+schottky) | ALREADY ACQUIRED 2026-08-14, zeroed here to avoid double-counting. 470 uF at the servo feed absorbs stall transients that would brown out the Pico through the shared 5 V rail; 100 nF on the ADC divider tap. | 0 | $0.00
100 kohm / 47 kohm 1% resistors (ON HAND - see Already Acquired) | Amazon | 1% metal-film | Buy (https://www.amazon.com/s?k=100k+62k+1%25+metal+film+resistor) | ALREADY ACQUIRED 2026-08-14, zeroed here. Battery divider to GP26. Values are hard-coded as WYV_VBAT_DIV_TOP/BOT in wyvern_config.h - confirm the on-hand parts are actually 100k and 47k before soldering, or the cutoffs shift. | 0 | $0.00
DaierTek 20 mm SPST round rocker arming switch, UL-listed (5-pack) | Amazon | B07S1MV462 | Buy (https://www.amazon.com/s?k=mini+SPDT+slide+switch) | 2026-08-13: KCD1, 20 A class. Carries full pack current (~1.9 A) plus UBEC and bulk-cap inrush, so the rating is large margin. Mounted inside the Upper BT and reached by pulling the nose cone, not through the skin. 5-pack covers flight + both ground stands + spares. | 1 | $6.39
Subtotal
3. TVC - flight (servo, 2-axis gimbal)
Item | Storefront | Part # / Spec | Link | Note | Qty | Unit ($) | Line ($)
EMAX ES08MA II metal-gear analog micro servo (4-pack) | Amazon | B07KYK9N1G | Buy (https://www.amazon.com/gp/product/B0DN1G3P2M) | Cart reconciliation 2026-08-09e: cart has qty1 (1x 4-pack = 4 servos), not 2 - reduced from qty2. Flight+spare design intent (qty=8) not currently covered by cart; confirm if 2nd pack still needed. | 1 | $39.99
XIKE MR105-2RS ball bearings (gimbal, 10-pk) | Amazon | B09DJY425B | Buy (https://www.amazon.com/gp/product/B09DJY425B) | 2026-08-13: qty2 in cart = 20 bearings. Gimbal uses 4 (two per axis); rest are spares and ground-rig stock. | 2 | $6.99
uxcell M2 / 15 mm linkage tie rod end ball head joint (4 pcs, red) | Amazon | B07Q2WHMWK | Buy (https://www.amazon.com/gp/product/B07Q2V3R61) | RE-SOURCED 2026-08-14 (final): B07Q2WHMWK is the same uxcell M2 x 15 mm rod end as the original B07Q2V3R61, red instead of blue, 4 pcs per pack, in stock. qty2 = 8 rod ends against the 2 the gimbal needs. GEOMETRY RESTORED: 15 mm, so the earlier 19 mm pushrod-length concern is void and the original linkage sizing stands. Verify the cart price against $12.99 at checkout. | 2 | $12.99
Honbay 300 mm servo extension leads (10-pk) | Amazon | B01LA9YDEI | Buy (https://www.amazon.com/gp/product/B01LA9YDEI) | 2026-08-13: qty1 in cart. Doubles as the M-F extension stock for the servo signal and power leads that part at the bulkhead on ejection. | 1 | $6.99
Subtotal
4. Recovery (motor ejection - two-body-tube separation at the bulkhead joint)
Item | Storefront | Part # / Spec | Link | Note | Qty | Unit ($) | Line ($)
Estes 24 in rip-stop nylon parachute (FLIGHT canopy - CHUTE_D=0.6096 m in all sims) | Estes | 24in chute | Buy (https://www.estesrockets.com/) | 2026-08b: switched 18in->24in, descent 6.7->5.0 m/s. Only 1 needed (not 4) - confirmed 2026-08-09. | 1 | $9.23
Aramid (Kevlar) shock cord - 19 ft | Estes | Aramid 19ft | Buy (https://www.estesrockets.com/) |  | 1 | $9.00
Estes recovery wadding (72 sheets) | Estes | Recovery wadding | Buy (https://www.estesrockets.com/) | in cart (qty1) - matches design need exactly, confirmed 2026-08-09 | 1 | $5.40
Separation bulkhead (single, printed PC-FR) - release-force-calibrated joint between Lower BT / Upper BT, no bypass tube | In-house | PC-FR (printed) | Buy | 2026-08-09: bypass gas tube design retired. Single bulkhead is now the separation joint itself (see Recovery.md sec1,4). Printed in-house. | 1 | $0.00
Subtotal
5. Propulsion (Estes motors + launch system)
Item | Storefront | Part # / Spec | Link | Note | Qty | Unit ($) | Line ($)
Estes F15-4 2-ct (flight motor; 4 s delay + ejection = recovery) | Estes | F15-4 (2-ct) | Buy (https://www.estesrockets.com/) | 2026-08-14: one 2-ct pack added to the cart, and 2 motors are already on hand (see Already Acquired). Total 4 flight motors, which matches the F15-4 count in WYVERN_E4_GSE_TestStands.md section 5. Verify the Estes cart price - $33.99 is carried across from the F15-0 line. | 1 | $33.99
Estes F15-0 2-ct (ground stands; 0-delay plugged) | Estes | F15-0 (2-ct) | Buy (https://www.estesrockets.com/) | Static thrust curves + MTVC + servo TVC on the balance (jetvane dropped). | 5 | $33.99
Estes E16-4 2-ct (stand commissioning/calibration) | Estes | E16-4 (2-ct) | Buy (https://www.estesrockets.com/) | NOT IN CURRENT CART (2026-08-09) - commissioning motors, zeroed from to-buy total; still needed before Gate 5 stand commissioning | 3 | $0.00
Estes large engine plugs (40 ct) - plug F15-0 for ground | Estes | Engine plugs 40ct | Buy (https://www.estesrockets.com/) | Confirmed 2026-08-09: not actually needed. Zeroed and removed from active procurement. | 1 | $0.00
Estes STARTech starters (igniters) | Estes | STARTech | Buy (https://www.estesrockets.com/) | Confirmed 2026-08-09: not actually needed. Zeroed and removed from active procurement. | 5 | $0.00
Estes Pro Series II Launch Controller | Estes | Pro Series II LC | Buy (https://www.estesrockets.com/) | REIMBURSED - see Summary | 1 | $39.60
Subtotal
6. Airframe filament (Amazon + Bambu Lab; ASA-Aero / PETG-CF / PC-FR fly, the rest are RQ2 comparison + tooling)
Item | Storefront | Part # / Spec | Link | Note | Qty | Unit ($) | Line ($)
kexcelled Flame Retardant PC Filament (White FR, UL94 V0), Amazon - 1 kg | Amazon | B0FN7Z6FF1 | Buy (https://www.amazon.com/gp/product/B0FN8366S3) | 2026-08-13: in cart at $49.99. UL94 V0 halogen-free PC-FR - this is the TVC assembly material (motor mount, gimbal). White, not black; cosmetic only. | 1 | $49.99
ASA Aero (White 46100), Bambu Lab filament w/ spool - 1 kg | Bambu Lab | White 46100 | Buy (https://us.store.bambulab.com/) | 2026-08-13: Bambu Lab store item, NOT in either cart pasted today (Bambu is a separate storefront). Still required - ASA-Aero is the upper and lower body tube material. Amazon equivalent B0C9RC7SJG if you want off Bambu. | 1 | $49.99
eSUN ABS+ Filament (Black) - DROPPED | Amazon | B07FQ5MC78 | Buy (https://www.amazon.com/gp/product/B0C7BW71L8) | DROPPED 2026-08-14 at program direction. ABS is removed from RQ2 entirely: the zoned-materials study is now ASA-Aero / PETG-CF / PC-FR against plain PC, and the blast-shield screen drops from six materials to five (PLA, PETG-CF, ASA-Aero, PC, PC-FR). Update Build_Guide and GSE_TestStands to match. | 0 | $0.00
ANYCUBIC PC Filament (Black), Amazon - 1 kg | Amazon | B0FPQ7V6T3 | Buy (https://www.amazon.com/gp/product/B0FB2KNC8P) | 2026-08-13: in cart at $31.99 (was $28.79). RQ2 comparison material (plain PC vs PC-FR) and blast-shield screen coupon. | 1 | $31.99
iSANMATE ASA Filament (Black), Amazon - 1 kg | Amazon | B0DB16JG74 | Buy (https://www.amazon.com/gp/product/B0D5MG8JDR) | 2026-08-13: in cart at $16.19 (was $17.99), limited-time deal. Plain ASA (Black) - NOT the same as Bambu ASA-Aero (row 52), which is the foamed low-density grade the mass cascade assumes. Use for fixtures and the RQ2 screen, not the airframe. | 1 | $16.19
ELEGOO Rapid PETG (Black), Amazon - 1 kg | Amazon | B0CPF7FDTG | Buy | 2026-08-13: NEW cart line. Plain PETG, NOT the PETG-CF that the lower body tube and fins are specified in (PETG-CF is in Already Acquired, 2 kg). Use for prototyping, jigs, fixtures and the RQ2 blast-shield screen - not flight structure. | 1 | $12.59
ELEGOO PLA-CF (Black), Amazon - 1 kg | Amazon | B0D86M3RM4 | Buy | 2026-08-13: NEW cart line. PLA-CF is NOT a flown material - the zoning is ASA-Aero / PETG-CF / PC-FR. Fine for tooling and as a sixth blast-shield screen coupon, but keep it out of the airframe: PLA HDT ~55 C is below the predicted engine-bay wall temperature. | 1 | $23.74
Subtotal
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

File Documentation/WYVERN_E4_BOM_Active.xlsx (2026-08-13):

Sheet: BOM
GTR70E WYVERN - Active Procurement BOM (only items actually being bought)
Trimmed copy of WYVERN_E4_BOM.xlsx, 2026-08-09f. Fully regenerated - adds HANGLIFE heat-set insert assortment (M2-M6, 345pc, $19.99) to Section 7, confirmed in the live Amazon cart. Contains ONLY line items with a real, nonzero cost confirmed in one of the live carts (Amazon/Adafruit/Estes/Bambu) or the custom PCB fab order. The master WYVERN_E4_BOM.xlsx remains the full historical record (including items still needed but not yet in a cart, e.g. the F15-4 flight motor and E16-4 commissioning motors - see that file before assuming procurement is complete).
1. Flight Computer & Sensors
Item | Storefront | Part # / Spec | Link | Note | Qty | Unit ($) | Line ($)
Raspberry Pi Pico 2 W (pre-soldered header) - flight FC + spare | Amazon | B0DP54FWX1 | Buy | 2026-08-09e: IS in live Amazon cart ($16.31, qty1 - corrected from qty2). Contradicts earlier "superseded, not being bought" note - real cart wins. Role unclear (bench/dev spare alongside custom RP2350B PCB, or KB2040 replacement) - confirm intended use before assuming it is flight hardware. | 1 | 16.31 | 16.31
BNO085 9-DOF external IMU (single unit, via PCB's one STEMMA-QT port; mounted at TVC/electronics boundary) | Adafruit | PID 4754 | Buy | in Adafruit cart (qty2 currently, 1 spare); design needs only 1 - PCB has a single STEMMA-QT port, not 3 IMU buses | 1 | 29.5 | 29.5
i3 4K Thumb Action Camera (64G card, self-contained ~36 g) | Amazon | i3 B0G4PD79FL (32G variant) | Buy | in cart (32G variant, i3 B0G4PD79FL) | 1 | 67.99 | 67.99
Subtotal |  |  |  |  |  |  | 113.8
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

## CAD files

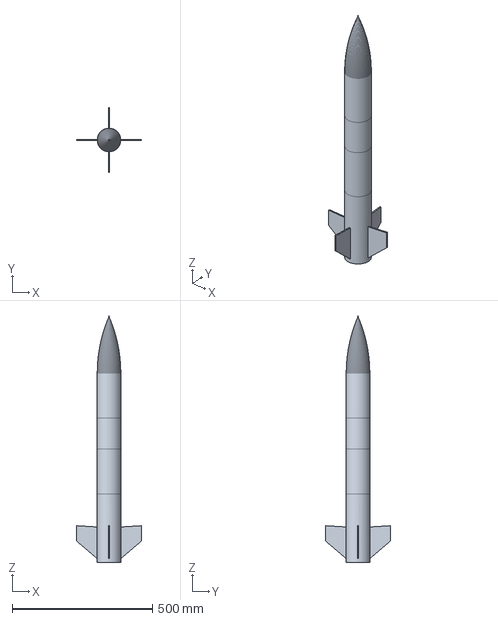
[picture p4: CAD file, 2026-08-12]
Past Iterations/WYVERN-E 3.0/3D parts/11_outer_shell_full.step
230.0 x 230.0 x 876.0 mm

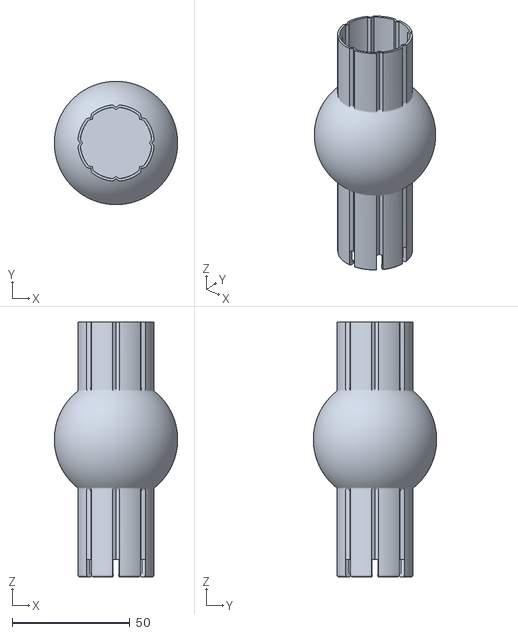
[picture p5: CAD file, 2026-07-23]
3D parts/MTVC/MTVC Assembly - Casing V3.stl
52.5 x 52.5 x 108.5

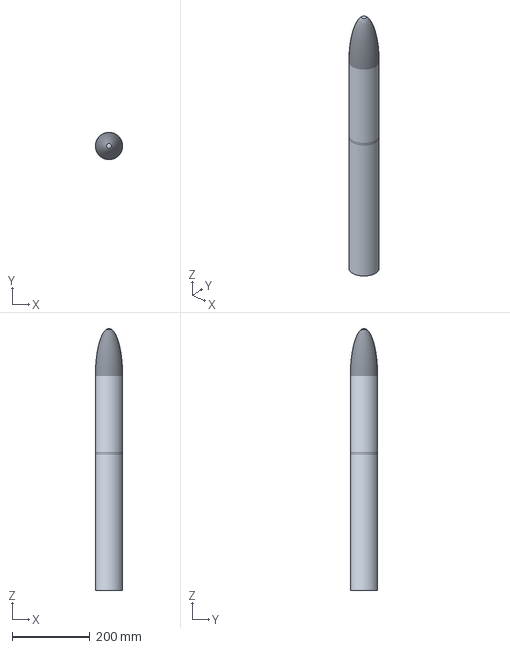
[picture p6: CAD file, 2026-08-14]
3D parts/00_full_assembly.step
69.9 x 70.0 x 672.4 mm

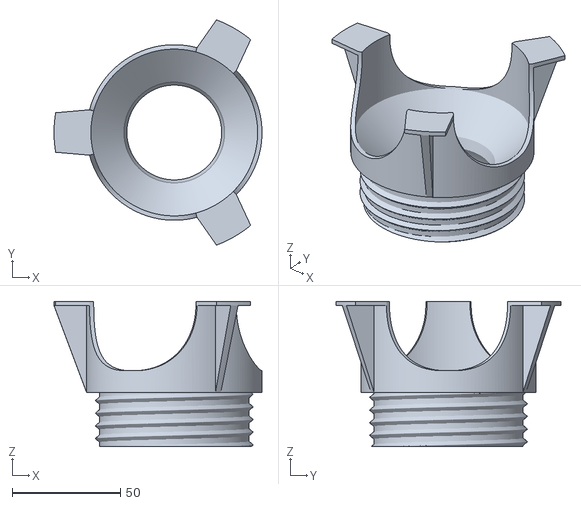
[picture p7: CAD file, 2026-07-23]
3D parts/MTVC/MTVC Assembly - Testing Stand V3.stl
95.9 x 103.8 x 67.0

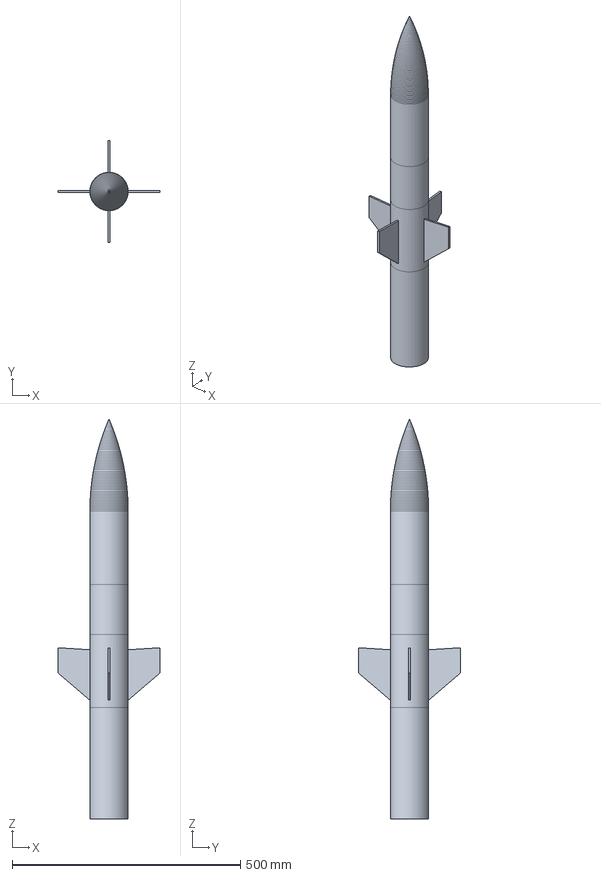
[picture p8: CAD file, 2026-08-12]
Past Iterations/WYVERN-E 3.0/3D parts/00_full_assembly.step
224.0 x 224.0 x 876.0 mm

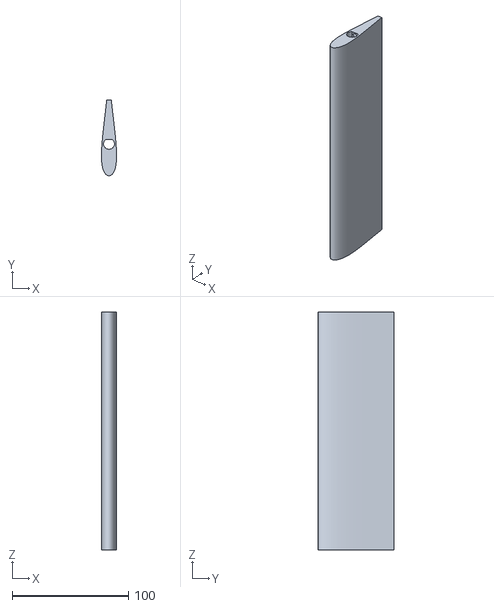
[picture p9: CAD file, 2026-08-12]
Past Iterations/WYVERN-E 3.0/Wind Tunnel/modular-wind-tunnel-for-stem-education-model_files/Smoke Struts and Wands/smoke-rake-full-span-strut.stl
13.0 x 65.0 x 204.5

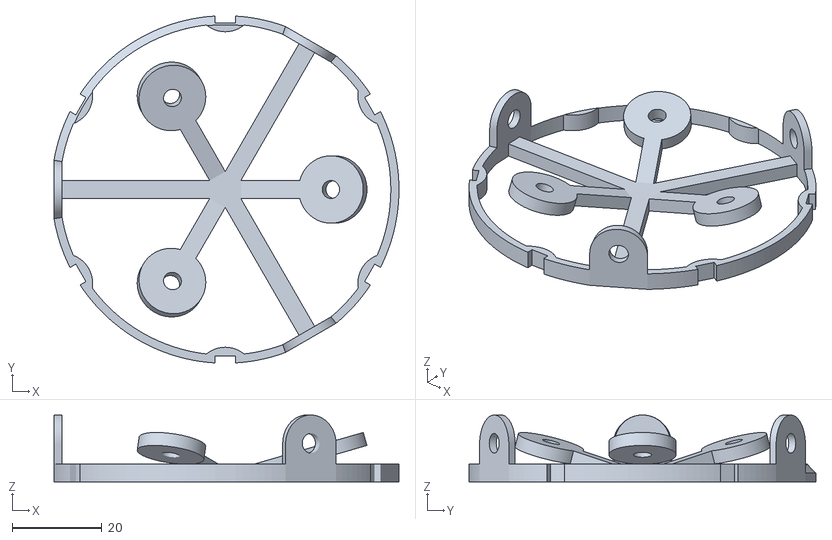
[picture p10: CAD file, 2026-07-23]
3D parts/MTVC/MTVC Assembly - Solenoid Frame V4.stl
76.9 x 77.3 x 14.9

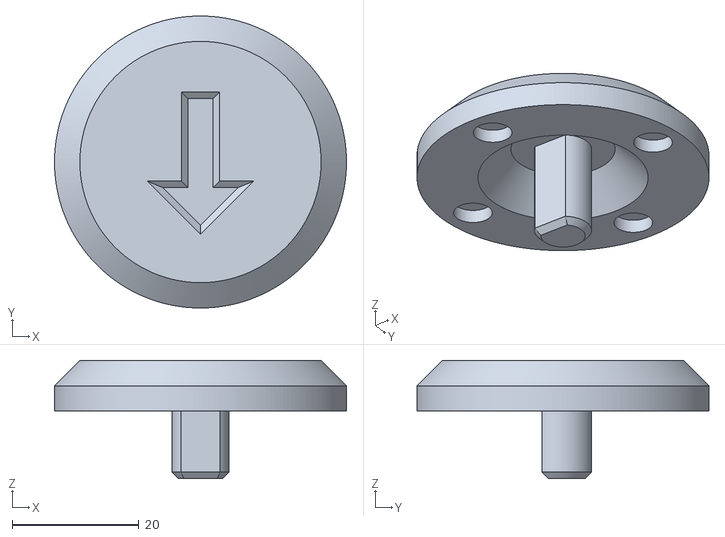
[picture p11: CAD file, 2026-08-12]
Past Iterations/WYVERN-E 3.0/Wind Tunnel/modular-wind-tunnel-for-stem-education-model_files/Smoke Struts and Wands/smoke-port-end-plug-mount-for-full-span-smoke-rake.stl
46.0 x 46.0 x 18.6

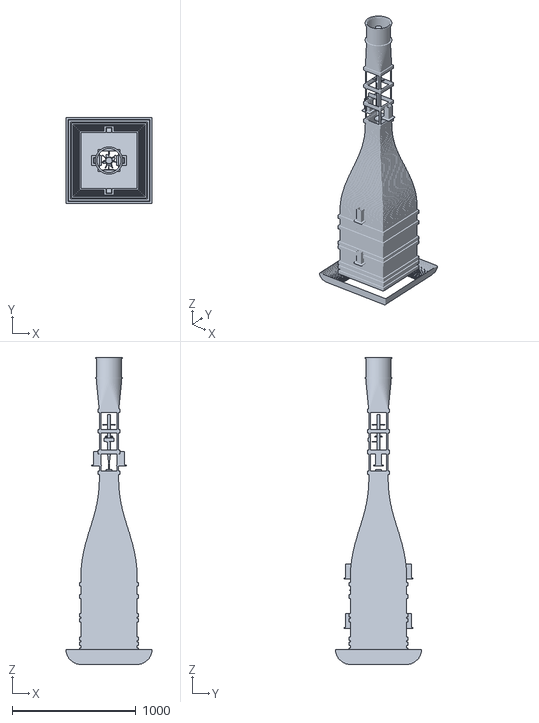
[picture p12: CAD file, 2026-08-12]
Past Iterations/WYVERN-E 1.0/Wind Tunnel/WindTunnel_all_parts/WYVERN_WindTunnel_FullAssembly.stl
695.7 x 695.7 x 2478.0

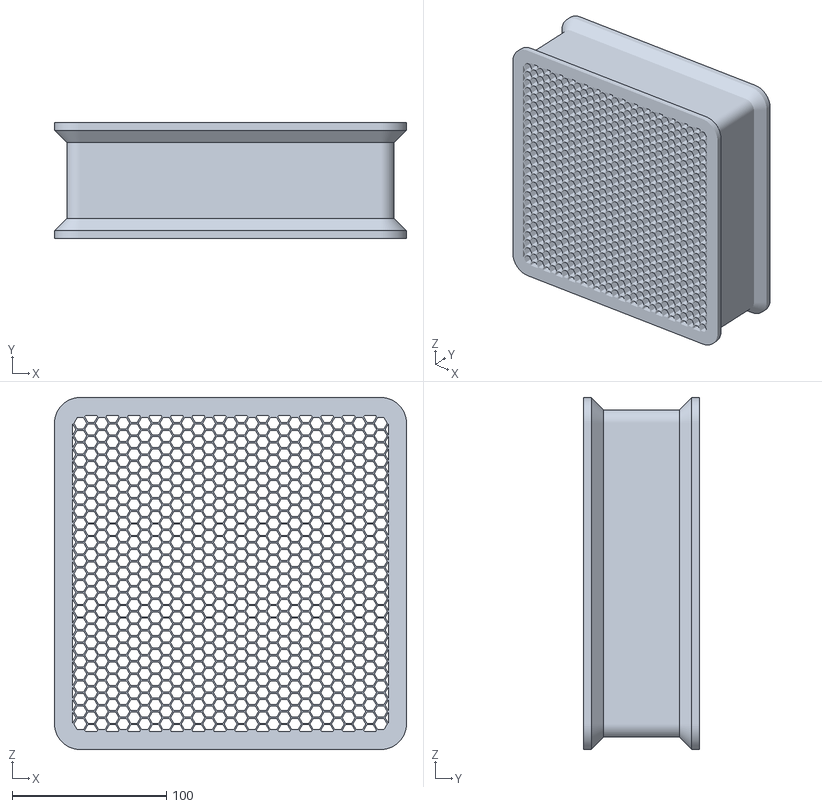
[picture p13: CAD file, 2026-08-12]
Past Iterations/WYVERN-E 3.0/Wind Tunnel/modular-wind-tunnel-for-stem-education-model_files/2a-honeycomb-flow-straightener-fully-modeled.stl
228.0 x 75.0 x 228.0

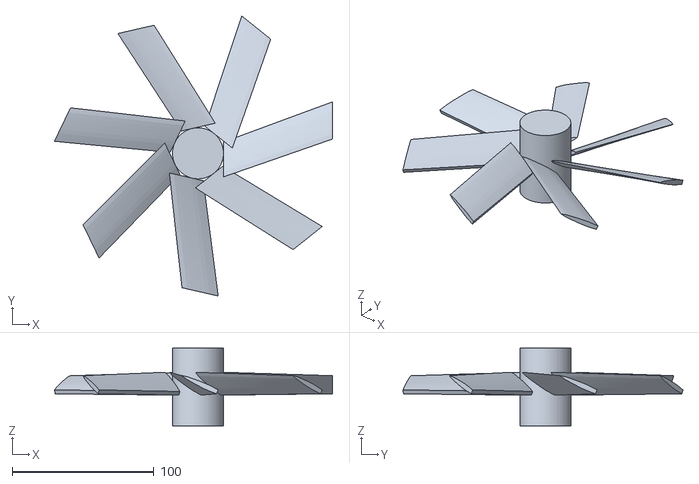
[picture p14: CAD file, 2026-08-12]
Past Iterations/WYVERN-E 1.0/Wind Tunnel/WindTunnel_all_parts/10_fan_assembly_7blade.stl
196.3 x 197.6 x 55.0

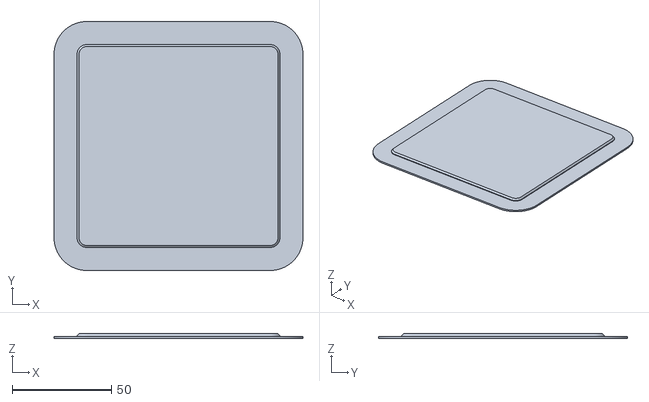
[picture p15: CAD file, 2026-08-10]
Wind Tunnel/STEM+Tunnel+Promo+-+0.4n_stls/obj_102_Assembly.stl
125.6 x 125.6 x 2.40

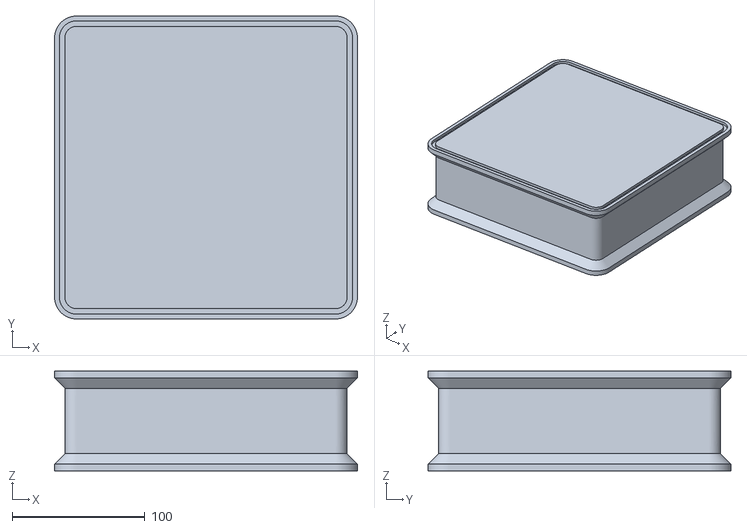
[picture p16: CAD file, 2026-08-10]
Wind Tunnel/STEM+Tunnel+Promo+-+0.4n_stls/obj_28_Assembly.stl
228.0 x 228.0 x 75.0

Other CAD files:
3D parts/MTVC/MTVC Assembly - Tube.gcode.3mf
3D parts/MTVC/MTVC Assembly - Casing.gcode.3mf
3D parts/MTVC/MTVC Assembly - Casing V2 WHITE.gcode.3mf
Wind Tunnel/STEM+Tunnel+Promo+-+0.4n_stls/obj_9_Smoke Rake - Full Span Strut.stl
Wind Tunnel/STEM+Tunnel+Promo+-+0.4n_stls/obj_98_Smoke Port End Plug Mount for Full Span Smoke Rake.stl
3D parts/00_full_assembly.stl
3D parts/01_nose_cone_ellipsoid_ASA.step
3D parts/01_nose_cone_ellipsoid_ASAAero.step
3D parts/01_nose_cone_ellipsoid_ASAAero.stl
3D parts/02_recovery_bay_ASA.step
3D parts/02_upper_bt_avionics_ASAAero.step
3D parts/02_upper_bt_avionics_ASAAero.stl
3D parts/02b_fc_card_carrier_aft_ASAAero.step
3D parts/02b_fc_card_carrier_aft_ASAAero.stl
3D parts/02b_fc_card_carrier_fwd_ASAAero.step
3D parts/02b_fc_card_carrier_fwd_ASAAero.stl
3D parts/03_fc_bay_ASA.step
3D parts/03_lower_bt_chute_tvc_ASAAero.step
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

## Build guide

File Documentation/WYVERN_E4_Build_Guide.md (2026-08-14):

---
updated_at: 2026-08-01
---

# GTR70E WYVERN, Build, Bench and Range Guide

**Authors:** Swaroop Sahoo, Chris Liu, Allison Hong  
**Program:** GTR70E WYVERN

##### Companion to `WYVERN_E4_Timeline_14Day.md`. Sections map to timeline days.

Every parameter below is the frozen value from `CONFLICTS.md` §4. If this guide and that table ever
disagree, **the table wins**, and the disagreement is a defect worth fixing before you build.

---

## A · Print (Timeline Days 4–6)

### A1 Material zoning, get this right or the thermal margin is gone

The airframe is two body tubes (Lower BT, Upper BT) joined at one bulkhead — see
`WYVERN_E4_Recovery.md` §1. The bulkhead is the separation joint and takes the ejection gas directly.

| Part | Material | Why |
|---|---|---|
| Nose cone, recovery bay tube, FC bay tube (upper body, avionics housing) | **ASA-Aero** (foamed, ~0.65 g/cm³) | No motor heat, no gas load. Lightest zone in the stack. |
| Lower body tube, 4 fins (87 mm) | **PETG-CF** (~1.30 g/cm³) | Sees the ejection-gas path and takes the fin aerodynamic load; stiffer than ASA-Aero at the fin root. |
| Bulkhead (single separation joint) | **PETG-CF** | Takes the ~140 kPa ejection pulse directly and is sized to **release** at a target force, not just survive one, see `WYVERN_E4_FEA_Structural.md` §4 (open item). |
| TVC assembly, motor mount, gimbal | **PC-FR** (~1.20 g/cm³) | Sustained plume heating, fire-retardant grade for the zone closest to the motor. |

### A2 Print settings

- Nozzle 0.4 mm, layer 0.2 mm, 4 walls, 25% gyroid infill.
- **Fins: print flat, 100% infill, and orient so layer lines run spanwise**, a fin that delaminates
  along a chordwise layer line at 36 m/s is a lost vehicle.
- PETG-CF needs an enclosure and a 100–110 °C bed. Dry it first; PC absorbs water and prints badly wet.
- PLA foams on extrusion, run the vendor's recommended flow, not your usual ASA profile.

### A3 Print checks before you assemble

- [ ] Body tubes: check OD 70 mm and roundness at three stations. Ovality kills the friction fit at the bulkhead joint.
- [ ] Bulkhead: servo-extension and STEMMA-QT cable pass-through holes are clear and to size (see `WYVERN_E4_Recovery.md` §1, §5).
- [ ] Fin root: fits the slot without forcing. Forced = pre-stressed = cracks under load.
- [ ] Gimbal: pivots freely through the full range with no binding. **Check this before wiring.**
- [ ] Weigh every part and compare against `3D parts/_generator/mass_report.json`.
      More than ~10% over on a bay tube means over-extrusion, and it comes straight off your margin.

---

## B · Bench bring-up (Timeline Day 7), Gate 2

Run these in order. **Do not skip ahead**; each test assumes the previous one passed.

### B1 Toolchain

Arduino IDE → Board Manager → install **Arduino-Pico (earlephilhower)**. Select
**"Raspberry Pi Pico 2 W"** (`rpipico2w`) — the module this build
actually uses, **not** any Pico/Pico 2 W module profile (those assume the wrong GPIO count and a
radio chip that isn't populated here). Library Manager → install `Adafruit_BNO08x`,
`Adafruit_BNO08x`, `Adafruit_BME680`, `Adafruit_BMP3XX`. `Servo`, `Wire`, `SPI`, `SD` ship with the core; `WiFi` is
only needed if `WIFI_ENABLED` is ever flipped on for a future board rev with a radio chip.

```
cd "Flight Computer/test_code"
python3 -m pip install pyserial
```

### B2 `t1_i2c_scan`, is anything on the bus?

Expect: PCA9548A at **0x70** on I2C0, and the external BNO085 (STEMMA-QT, bulkhead-boundary mount)
at **0x4A** on I2C1.

| Symptom | Cause |
|---|---|
| Nothing on I2C0 | Mux unpowered, or SDA/SCL swapped (GP16 = SDA, GP17 = SCL) |
| 0x70 but no channel devices | Mux channel not selected, or sensor 3V3 not connected |
| Nothing on I2C1 | GP18/GP19 swapped, or the external IMU is on the mux by mistake, it must be on its **own** bus |

### B3 `t2_imu_grv_deflection`, do the IMUs agree?

Enables Game Rotation Vector on both. Hold the airframe still: body and external quaternions should
agree within ~1°.

> **Magnetometer must stay off.** GRV mode is accel+gyro only, deliberately, the servos' magnets
> will corrupt any magnetically-referenced heading.

### B4 `t3_servo_sweep`, **calibrate the linkage. Do not skip this.**

Skipping this step is how the linkage ends up mechanically limited to less than the firmware's
commanded ±8°, which quietly eats your control authority without throwing any error.

1. Flash `t3_servo_sweep.ino`, open Serial Monitor at 115200.
2. Send `c`. Adjust the linkage so the nozzle sits **mechanically centred** at 1500 µs.
3. Send `p`. The servo steps to +8°, 0°, −8°, holding 3 s at each.
4. **Measure the actual nozzle angle** at the +8 and −8 holds with a digital protractor.
5. If measured ≠ 8.0°, set `SERVO_LINKAGE_RATIO = 8.0 / measured_deg`, reflash, repeat from 2.
6. Send `y`, repeat for yaw.
7. Send `s` for the continuous sweep. **Listen**, buzzing or stalling at the extremes means the
   linkage binds before the commanded limit.
8. **Copy the final `SERVO_LINKAGE_RATIO` into `wyvern4_tvc.ino`.** Record it in the build log.

- [ ] Pitch reaches ±8.0° measured, no binding
- [ ] Yaw reaches ±8.0° measured, no binding
- [ ] `SERVO_LINKAGE_RATIO` copied into the flight sketch

### B5 `t4_sensors_sdlog`, does the card actually take data?

Confirm BMP388 and BME688 both read, and that a file appears on the card with plausible rows.
Use a **class 10 or better** card. A slow card is the one thing that can still make the log ring
back up (watch `peak=` in the heartbeat).

### B6 Full self-test, Gate 2

```
python3 selftest.py /dev/ttyACM0 # or /dev/tty.usbmodemXXXX on macOS
```

Every row must be PASS (WIFI may be SKIP, RBF may be WAIT until you pull the pin):

```
MUX · IMU_EXTERNAL · IMU_BODY · IMU_MINIMUM · BARO_BMP · BARO_BME
SERVO · CORE0_READY · BATTERY · SD · WIFI · RBF · LOG_RING
```

**`LOG_RING` matters.** It verifies core 1 is actually draining core 0's log ring; without that, a
flight produces a CSV containing only a header while reporting nothing wrong on the surface. If
`LOG_RING` fails, do not fly — you will get no data.

Watch the heartbeat: `HB:... drop=0 pend=<small> peak=<small>`. `peak` climbing toward 256 means the
card can't keep up.

- [ ] **`>>> PREFLIGHT GO <<<`**

### B7 Bench gotchas

| Symptom | Cause |
|---|---|
| Never leaves BOOT | Self-test failed, RBF still inserted, or battery below 6.0 V |
| `BATTERY: FAIL` on a good pack | GP26 divider not wired, the ADC pin is floating. Check the schematic against the harness. |
| Instant launch detect on the pad | GP7 LAUNCH_IRQ floating low. Wire the switch or remove the branch. |
| `drop` climbing | Slow SD card. Raise `FLUSH_EVERY` or use a faster card. |

---

## C · Airframe assembly (Timeline Day 8)

1. **Bulkhead joint.** Route the servo extensions and STEMMA-QT cable through the pass-through holes
   before final fit, decide slack vs. breakaway connector per `WYVERN_E4_Recovery.md` §5 first, this
   is much harder to redo after the tubes are together. The joint itself is friction-fit/shear-pinned
   to **release** under ejection pressure, not sealed shut, see `WYVERN_E4_FEA_Structural.md` §4 for
   the (still-open) release-force sizing.
2. **TVC bay.** Motor mount + gimbal into the Lower BT. Confirm the gimbal still moves freely after
   bonding.
3. **Fins.** Four, 90° apart. **Alignment matters more than strength here**, a misaligned fin set
   induces roll, and roll couples into the pitch/yaw loops the whole experiment is measuring.
4. **Rail buttons**, 1010, aligned along one fin line.
5. **Recovery.** Chute, 1/8″ Kevlar shock cord, Nomex protector, wadding on both faces of the
   bulkhead joint. Pack so the chute cannot snag the cable pass-through.
6. **Bulkhead release-force check.** Test the joint's separation force by hand before flight: it
   should take firm but not two-handed effort, targeting the 50–150 N band in
   `WYVERN_E4_Recovery.md` §4.

---

## D · Ground separation test (Timeline Day 9), Gate 3

**Do this before you fly. It is the single point of failure in the entire recovery system.**

The FC does not fire anything, recovery is the F15-4's own charge, separating the two body tubes at
the bulkhead joint. There is no electronic backup. If this path doesn't work, the vehicle comes down
ballistic.

1. Assemble fully, chute packed, **no flight battery, no camera** (don't risk them).
2. Fire a representative ejection charge (or the motor's own charge, restrained) into the Lower BT.
3. Confirm: bulkhead joint releases cleanly in the 50–150 N band · chute deploys fully · servo/
   STEMMA-QT cable pass-through survives the separation without snagging or damage · no scorching
   past the wadding.
4. If the joint sticks: reduce the friction fit. If it releases too easily: increase it.
   **Retest after any change.**

- [ ] Clean separation, chute deployed, cable pass-through intact

---

## E · Ground test stands (Timeline Days 7–9)

### E1 Dead-weight calibration, Gate 4, before any motor

Never put a motor near an uncalibrated stand.

1. Hang known masses spanning the expected range on each channel (axial to ~25 N, lateral to ~4 N).
2. Record counts vs force, fit the transfer function per channel.
3. The 3-axis balance needs the **full 3×3 matrix**, not three independent scalars, the flexures
   are cross-coupled. `Documentation/derive_math.py` derives it; `MATH_DERIVATIONS.md` explains it.
4. Expect the fit to resolve thrust to <1 mN and deflection to ~0.01°.

- [ ] All channels calibrated, residual < 1%

### E2 Commissioning, Gate 5, 2 × E16-4 per stand

Compare the measured curve against the published E16 curve. Within ~10% on total impulse and peak.

> **Watch for mount ringing.** The bench model (`wyvern_datagen/bench_sim.py`) predicts a **42 Hz**
> mount resonance, and at the HX711's 80 SPS rate the Nyquist is 40 Hz, so the ring **aliases** and
> will appear as a spurious low-frequency wobble on the thrust trace. If you see it: stiffen the
> mount, or drop the HX711 to 10 SPS and accept the lower bandwidth. Do not just smooth it away, 
> you'd be smoothing away real ignition-transient data too.

### E3 RQ1, actuator A/B (Timeline Day 9)

The program's headline experiment. Same fixture, same electronics, same control law; only the
actuator changes.

For each actuator class (magnetic-solenoid, then servo), 3 × F15-0:
- Step commands: 0 → +5°, hold, → −5°, hold
- Ramp: continuous sweep across the full ±8°
- PID disturbance rejection: 3° mount tilt, let the loop null it

Extract per actuator: **bandwidth, slew rate, step overshoot, steady-state error, max achievable
deflection.** Log commanded vs measured throughout, that difference is the result.

> **While you are here, settle the servo torque question.** The deep-sim now reports only **2.3×**
> margin against servo stall at the full ±8° (the old 3.7× was computed at 5°, understating the
> hinge load by 1.6×). This rig measures it directly. At the ±8° extremes under thrust, record
> servo current and whether the nozzle actually **holds** the commanded angle. If it droops:
> reduce the linkage ratio, or move the servo rail to 6 V, or fit a higher-torque servo, in that
> order. See `WYVERN_E4_BUILD_READINESS.md` §11.

### E4 RQ2, zoned materials (Timeline Days 7 and 9), jetvane blast-shield screen

RQ2 is the material justification for the zoning actually flown (ASA-Aero upper body, PETG-CF
lower body and fins, PC-FR TVC assembly), plus a jetvane materials screen on the static-fire stand,
run as a blast-shield coupon test (see `WYVERN_E4_GSE_TestStands.md` §1). Print bend coupons in
all three flown materials plus the extra RQ2 comparison materials (PLA, PC), and five coupon plates
for the blast-shield screen.

- **Bend to fracture** (Day 7, no motor needed): 2.0 × 15 × 100 mm coupons, printed flat, identical
  print parameters across materials, same nozzle, layer height, wall count and infill. Simply
  support each on two 6 mm rollers at an 80 mm span, hang a string and yoke from mid-span, and add
  dead weight in 500 g steps until it snaps. Record the mass at fracture. Five coupons per material.
  Fixture and full sizing are in `WYVERN_E4_GSE_TestStands.md` §5; the conversion for this exact
  geometry is $\sigma_f\,[\text{MPa}] = 19.6\,m\,[\text{kg}]$, and the fixture is built to 6 kg
  against a worst case near 5 kg. This is the data behind why the TVC assembly is PC-FR and not
  PETG-CF or ASA-Aero. No load cell is involved — dead weight is the force reference.
- **Engine-bay wall temperature** (Day 9, during the static fires): tape a thermocouple to the
  inside of the engine-bay wall and log peak temperature across the 3.45 s burn. Compare against
  ASA-Aero's lower HDT and PETG-CF's ~80 °C. The model predicts a wall temperature comfortably
  under PETG-CF's limit; if the measurement runs much higher, that is a finding worth reporting
  and it validates the zoning decision directly.
- **Jetvane blast-shield screen** (static-fire campaign): a flat coupon
  plate of each candidate material, 5 mm thick at 100% infill, mounted directly in the exhaust
  path like a blast shield and fired on. Five materials go through the screen: PLA, PETG-CF,
  ASA-Aero, PC, and PC-FR; ABS was dropped 2026-08-14. Response measured is melt-through, ablation
  depth, and slag buildup, not thrust or deflection. Materials that survive 5 mm without melting
  through are retested at 4 mm, then 3 mm, then 2 mm, until they fail, giving a failure-thickness
  ranking across all five.
  Feeds directly into RQ2 as a materials-selection data point independent of the flight airframe.

---

## F · Range procedure (Timeline Day 11)

### F1 Go / no-go, all must be YES

- [ ] Wind < 5 m/s, gusts < 2 m/s above mean *(hard stop 7 m/s)*
- [ ] Ceiling > 300 m, no precipitation
- [ ] Ejection test passed (Gate 3)
- [ ] `selftest.py` → **PREFLIGHT GO** in flight configuration
- [ ] Battery > 7.4 V
- [ ] Mass 698 ± 15 g, CG 50.1 ± 1 cm from nose, **measured, not assumed**
- [ ] SD card inserted, empty, seated
- [ ] Camera charged, lens clean
- [ ] RSO briefed, range clear, ≥ 3 m standoff
- [ ] **Anemometer ready, you must record the surface wind at launch** (RQ3 needs it)

### F2 Pad sequence

1. Rocket on the rail, rail buttons free-sliding.
2. Power the FC. **Igniter is NOT installed yet.**
3. Run `selftest.py`. Confirm GO.
4. Pull RBF → state goes ARMED, camera starts.
5. Confirm heartbeat: `state=ARMED batt>7.4V rbf=1 drop=0`.
6. **Record wind speed and direction. Write it down.**
7. Clear the pad. Install the igniter last.
8. Launch on the RSO's call.

### F3 Immediately after recovery

1. Photograph the vehicle **before touching it**, fin condition, nose seat, any scorching.
2. Note where it landed relative to the pad (drift, for the dispersion check).
3. Power down, pull the SD card.
4. **Copy the CSV to two places before doing anything else.**
5. Note anything anomalous while it's fresh: sounds, visible tumble, deployment timing.

### F4 Same-evening reduction

```
cd Simulations
python3 we4_flight_reduce.py FLIGHT_A.csv FLIGHT_B.csv \
        --wind <measured_m_s> --label gainA gainB
```

Produces the RQ3 and RQ4 numbers, the health check, and the figures, into `plots_flight/`.

**Sanity-check the health block before you trust anything else:**

| Field | Expect | If not |
|---|---|---|
| `dropped_frames` | 0 | Data has gaps, note in the paper |
| `loop_dt` median | ~2000 µs | Control loop didn't hold 500 Hz |
| `loop_overrun_pct` | < 1% | Investigate before trusting RQ4 |
| `batt` start → min | > 7.0 V | Sag under servo load; check decoupling |

---

## G · Gain sets for RQ4

| Flight | Kp | Ki | Kd | Rationale |
|---|---|---|---|---|
| A | **0.10** | **0.40** | **0.18** | Flight gains. PM 44.7°, GM 12.6 dB at all 24 operating points. |
| B | 0.10 | 0.05 | 0.05 | The margin-search alternative: much higher margin (PM 49.7°) but ~2.3× the gust deviation. Tests whether extra stability margin costs real tracking performance. |

Change gains **only** in `wyvern_pid_defaults` in `wyvern_pid.h`. Reflash, re-run `selftest.py`,
and **record which gain set is on the vehicle**, mixing this up loses RQ4 entirely.

---

## H · If something goes wrong

| Symptom | Likely cause | Action |
|---|---|---|
| CSV has only a header | Log ring not draining | Check `LOG_RING` in self-test. Do not refly until it passes. |
| No BOOST in the log | Launch detect never fired | Check accel report enabled; check the 2 g threshold against actual peak specific force ~3.70 g (T/W ≈3.70) |
| Gimbal never moved | TVC inhibited | Check state reached BOOST and t ≥ 0.5 s; check servo power |
| Deflection clipped at 5° | The old ±5° clamp is back | Confirm you flashed the fixed `wyvern4_tvc.ino` |
| Chute didn't deploy | Ejection path blocked | **Do not refly.** Repeat Gate 3 ground ejection test. |
| Pitch > 30° | Weathercock in too much wind | Check the recorded wind against the 5 m/s limit |

---

## I · Reference, frozen parameters

| Parameter | Value |
|---|---|
| Liftoff / dry mass | 720 g / 660 g |
| CG / CP / margin | 45.0 cm / 53.3 cm / +1.14 cal |
| Apogee | 124.6 m (409 ft) @ 6.72 s |
| Burnout | 3.45 s, 68.7 m, 33.7 m/s |
| v_max / Mach | 34.5 m/s / M0.101 |
| Deploy | t = 7.45 s, +0.78 s past apogee, 7.7 m/s |
| Descent | 4.8 m/s under 24″ chute |
| PID | Kp 0.10 / Ki 0.40 / Kd 0.18, τ_d 0.02 s, i_lim 0.4 |
| Gimbal limit | **±8.0°** |
| Control rate | 500 Hz, core 0 |
| Launch detect | \|a\| > 2 g sustained ≥ 50 ms |
| Battery | 2S 450 mAh, warn 6.4 V, inhibit 6.0 V |

Full pin map: `CONFLICTS.md` §4.

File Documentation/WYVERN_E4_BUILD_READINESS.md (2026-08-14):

# GTR70E WYVERN, Build-Readiness Report

**Authors:** Swaroop Sahoo, Chris Liu, Allison Hong  
**Date:** 2026-08-12  
**Program:** GTR70E WYVERN

##### Cross-check of all project files against the current (rev-latest) design, build in 1 week, launch in 2

## 1. Verdict

The airframe is two body tubes (Lower BT, Upper BT) joined at one bulkhead. Every project file
(docs, BOM, firmware, CAD, wiring, simulations, proposal) reflects this single canonical
configuration. The remaining work is *fabrication + a short bench/ground-test punch-list* (§6),
plus the bulkhead release-force/cable-slack decisions in `WYVERN_E4_Recovery.md` §4–5. The 1-week
build / 2-week launch schedule in §7 is scoped against that punch-list.

## 2. Canonical configuration (single source of truth)

| Parameter | Value |
|---|---|
| Airframe | 70 mm OD, ~0.672 m, single stage, **two body tubes (Lower BT, Upper BT) + one separation bulkhead** |
| Liftoff / dry mass | **720 g / 660 g** |
| Motor (flight) | **Estes F15-4** ×4 (4 s delay + ejection charge = recovery) |
| Motor (ground) | **Estes F15-0** ×13-20 (plugged; static thrust curves + MTVC + servo TVC on the balance + jetvane blast-shield screen) |
| Commissioning | Estes/AeroTech **E16-4** ×6 |
| Apogee | **~409 ft / 124.6 m @ 6.72 s** (RK4(2e-4)+Barrowman) |
| v_max / Mach | **37.1 m/s / Mach 0.108** |
| Max acceleration | **2.71 g** net (3.70 g specific force = peak T/W) |
| T/W | **2.04 avg / 3.58 peak** |
| Fins | 4 × **87 mm** PETG-CF, root 70 / tip 35 / LE-sweep 25° |
| Stability | CG 45.0 cm / CP 53.3 cm → **+1.14 cal** (→1.5 cal burnout), no ballast |
| Materials | **ASA-Aero**: nose, Upper BT tube, Lower BT tube · **PETG-CF**: fins, separation bulkhead · **PC-FR**: TVC assembly, motor mount, gimbal |
| Recovery | **F15-4 motor ejection** separating the two body tubes at the bulkhead joint; deploy t≈7.45 s (+0.58 s past apogee, ~5.7 m/s); 24″ chute → ~4.7 m/s; no RRC3/9 V/CO2/e-match |
| Flight computer | **Raspberry Pi Pico 2 W** on a 20×24 (50×70 mm) perfboard, dual-core RP2350, 500 Hz TVC PID **Kp0.10/Ki0.40/Kd0.18**, ±8° gimbal |
| Sensors | **BNO085** ×2 (bay 0x4B, gimbal 0x4A via STEMMA-QT), **BME688** 0x76 + **BMP388** 0x77 baros, microSD on SPI1, i3 4K Thumb Action Camera; telemetry logged, WiFi bench-only |
| Structural margins | flight min SF ~340×; bulkhead separation-joint release-force sizing and direct-gas thermal check are **open items**, see `WYVERN_E4_FEA_Structural.md` §4; engine-bay thermal < HDT |
| Servo torque margin | **2.3× at the full ±8° gimbal** (0.086 N·m hinge vs 0.20 N·m stall), below the 3.0× gate, see §11 |

## 3. Per-target readiness

### 3.1 Flight computer, READY to build
- Firmware sketch `gtr70e_wyvern_tvc/` complete: main `.ino` + 10 header tabs, brace/paren balanced,
  no CO2/RRC3 includes (recovery is passive). PID gains margin-verified (`PID_TUNING_REPORT.md`).
- Wiring: `gen_wiring4.py` + `gen_connected_sch.py` regenerate a balanced `.kicad_sch` + preview,
  now consistent with firmware (BMP388 @3.3 V on mux ch3; GP1/GP6 spare; no 9 V/RRC3 block).
- Bench tests present: `t1_i2c_scan`, `t2_imu_grv_deflection`, `t3_servo_sweep`,
  `t4_sensors_sdlog` (now BMP388), plus `selftest.py`/`host_monitor.py` go/no-go harness.
- Telemetry: `telemetry_wifi_flight` + `telemetry_wifi_receiver` sketches.
- **PID: flight-ready, no change.** Gains **0.10/0.40/0.18** confirmed by both the frequency-domain
  margin analysis (`PID_TUNING_REPORT.md`, PM≈44.7°/GM≈12.6 dB) and a time-domain robust auto-tune
  (`PID_AUTOTUNE_REPORT.md`, within ~4% of grid-optimal; integral retained for steady-bias rejection).
- **Digital twin available:** `Simulations/wyvern_datagen/fc_sil.py` (+ GUI *Flight Computer SIL* tab)
  runs the full FC in software-in-the-loop with sensor noise and simulated Wi-Fi telemetry, use it to
  rehearse the flight and sanity-check the state machine before the pad.

### 3.2 Rocket airframe, READY per `gen_rocket4.py`
- `3D parts/` covers: nose (ASA-Aero), Upper BT, Lower BT, one separation bulkhead (PETG-CF, with
  servo-extension + STEMMA-QT cable pass-through holes), motor mount, 2-axis gimbal, 87 mm fins,
  1010 rail buttons.
- FEA (`WYVERN_E4_FEA_Structural.md` §4) covers flight loads (comfortable margin) but flags the
  ejection/separation-joint analysis as an open item pending the release-force sizing pass.

### 3.3 Wind tunnel, RESTORED TO PROGRAM (2026-08-10)
- The bench wind tunnel is back in scope, see `WYVERN_E4_GSE_TestStands.md` §4 and `CONFLICTS.md`
  §7 for the reversal record. Current rig is the STL/3MF kit in `Wind Tunnel/`, not the original
  Hofferth (2025) modular design that was struck.
- The airfoil-CFD package (`Simulations/CFD/`) is also restored, recovered from git history at the
  pre-deletion commit, solver re-run and re-verified (validation reproduces the documented NACA0012
  result), workbook recalculated clean.
- Aerodynamic characterization now runs three independent tracks: the Barrowman/drag-buildup model
  in the flight-sim suite, the 2D vortex-panel CFD in `Simulations/CFD/` (both predicted), and
  direct tunnel-measured lift/drag/stall (RQ3 in-situ) cross-checked against flight telemetry (RQ4).

### 3.4 Motor test stands, READY to print/build
- **Servo TVC stand** (`gtr70e_wyvern_gse_servo_rig`): base, thrust block, flexure template (PETG-CF).
- **Magnetic TVC stand** (`gtr70e_wyvern_gse_solenoid_rig`): separate physical rig, same flexure/DAQ chain as the servo stand, solenoid gimbal actuator swapped in for the RQ1 A/B comparison.
- **Static fire stand**: base plate, load-cell bracket, motor tower, steel blast deflector, plus a jetvane/material coupon rack (restored 2026-08-10, see `WYVERN_E4_GSE_TestStands.md` §1). Print PLA/PETG-CF baseline jetvanes and the PC/PC-FR comparison set alongside the coupon set (ABS dropped 2026-08-14).
- **Wind tunnel** (`Wind Tunnel/`): bench aerofoil rig for RQ3/RQ4, assemble per the STL/3MF kit in that folder.
- DAQ: Raspberry Pi Pico + load cells/HX711 (BOM §10); ground-rig sketches target Pico. Both TVC stands and the static-fire stand share the same DAQ chain for directly comparable data.

## 4. Bill of materials

`Documentation/WYVERN_E4_BOM.xlsx`, **9 live sections** spanning **all three build targets**: FC &
sensors, power, TVC (flight servo + ground magnetic A/B), recovery (motor ejection), propulsion
(F15-4 flight / F15-0 ground / E16-4 commissioning), airframe filament (ASA-Aero + PETG-CF + PC-FR),
harness/connectors/prototyping, the TVC balance + static stand, and the new §9 (custom PCB fab +
2026-08-09 cart reconciliation). **Former §9 (Hofferth wind tunnel) has been deleted** per the
2026-08 scope change and that section number reused for the cart-reconciliation section above.
Every live line has a purchase link and verified price. Filament allocation matches the material
zoning in §2.

**2026-08-09: reconciled against 3 live carts (Amazon $252.93, Adafruit $95.10, Estes $325.01) plus
a $175 custom PCB fab cost, added as new Section 9; corrected per follow-up feedback; then the
to-buy total was restricted to only what's actually in those 3 carts.** A handful of stale duplicate
line items from an earlier gap-fill pass were zeroed to avoid double-counting. Design-intent
quantities were corrected: 1 flight chute (not 4), 1 wadding pack (not 2), USB-C dust covers already
sufficient, and the BNO085 count drops to **1**, the custom PCB has a single STEMMA-QT port, so
there is one external IMU (mounted at the TVC-bay/electronics boundary, near the bulkhead joint), not
a gimbal+body+recovery+spare set. The Amazon 5kg load cell was dropped for the Adafruit one. Recovery
uses a single separation-joint bulkhead with no intermediate gas routing (see
`WYVERN_E4_Recovery.md`).

**Final pass (2026-08-09b): every to-buy line not present in one of the 3 carts was zeroed from
cost**, kept as a line item and flagged "NOT IN CURRENT CART" rather than deleted, so nothing
silently disappears from the procurement record. Airframe filament (Section 6) is the one explicit
exception and stays costed. **⚠ This zeroes the F15-4 flight motor (row 41) and the E16-4
commissioning motors (row 43)**, neither is in the given Estes cart, so they're zeroed from this
total, not from the build. They still need to be purchased separately before flight/commissioning.
Also zeroed: the Raspberry Pi Pico 2 W line (superseded by the custom PCB, already costed in
Section 9), BMP388, the old harness/prototyping line items (solder, wire, heat-set inserts,
breadboard, etc., none in the current carts), microSD breakout, 1010 rail, Nomex protector,
anemometer, and the steel blast deflector.

**2026-08-10: custom PCB fab cost updated to $200 for 3 boards** (was $195 for the same 3-board
run). Quantity was already 3 in the BOM; only the total fab price changed. One of the three boards
is earmarked for the ground servo TVC test stand rather than flight/spare use, worth noting in the
GSE build-out even though it doesn't change the BOM row itself. Total program spend rises by $5 to
match.

**2026-08-11: custom PCB revised, now Ø61 mm circular** (`PCB/`, fab package dated 2026-08-11,
supersedes `PCB/Archive 2.zip` from 2026-08-09, which is still sitting in the live folder pending
cleanup). Fits the Upper BT with ~2.9 mm radial clearance per side against the 70 mm OD / ~66.8 mm
ID airframe (`WYVERN_E4_Recovery.md` §1, `CONFLICTS.md` §7). No board-size figure existed anywhere
in the repo before this pass, so this isn't a correction to a prior number, it's the first time
diameter got written down. Cost/quantity (3 boards, $200 total) is unaffected by this revision.

**2026-08-11b: custom PCB fab cost updated to $207.01 for 3 boards** (was $200). Quantity
unchanged at 3; only the total fab price changed. Total program spend rises by $7.01 to
**$1,653.26**.

**2026-08-12: custom PCB diameter revised to Ø62 mm circular** (was Ø61 mm, per the 2026-08-11
pass above), to accommodate the larger `SS-12D10-G5` power switch footprint. Fit check against the
70 mm OD / ~66.8 mm ID Upper BT (`WYVERN_E4_Recovery.md` §1, `CONFLICTS.md` §7) now reads ~4.8 mm
diametral clearance (~2.4 mm radial per side), down from ~5.8 mm / ~2.9 mm at Ø61 mm — still clears.
Rocket/airframe OD is unaffected (70 mm, unchanged).

**2026-08-12b: fresh EasyEDA export confirms the Ø62 mm board and updates the fab cost.**
`PCB/Info_PCB_PCB1_2026-08-12.txt` (real export, supersedes the 2026-08-11 61mm×61mm snapshot):
board 62mm×62mm, 65 components (was 61), 36 devices (was 33), 50 nets (was 49) — the extra parts
account for the larger switch footprint and whatever else changed in this pass. Custom PCB fab cost
updated to **$231.72 for 3 boards** (was $207.01); quantity unchanged at 3. Total program spend
rises by $24.71 to **$1,677.97**. The standalone Hobbywing UBEC BOM line (§ Power) is now flagged
not-needed: PCB1's onboard TPS564201 buck already regulates 2S→~5V, so there's no second physical
regulator to buy.

**Filament pass (2026-08-09c):** Section 6 reconciled against the real Bambu Lab cart, PC-FR
($54.99), PC ($39.99), ABS ($19.99), ASA Aero ($49.99), all 1 kg, $164.96 total. **⚠ None of these
four match the current design's material scope.** PLA (primary airframe) and PETG-CF (TVC bay/
gimbal/bulkhead) are the only materials the design actually calls for as of the 2026-08b scope
change, when the RQ2 coupon-testing program (which needed PC-FR/PC/ABS/ASA-Aero) was dropped, 
see `CONFLICTS.md` §6. Added to the BOM as real cart items and flagged for confirmation rather than
assumed as flight-part material; if this is reserve stock or an RQ2-baseline archive, fine, but it's
not covering anything the current build needs. The "buy 2 more kg PLA" line was dropped, ~8kg
PLA/PETG-CF already acquired covers the airframe.

| Budget line | Value |
|---|---|
| Gross to-buy | $993.20 |
| Less reimbursed (launch controller) | −$39.60 |
| **Net out-of-pocket (still to buy)** | **$953.60** |
| Already acquired (owned) | $479.27 |
| **Total program spend** | **$1,432.87** |

> Rose from $1,725.46 on 2026-08-01 when the cart gap analysis found **five items the BOM never
> costed at all**, the microSD SPI breakout the firmware requires, the 1010 launch rail, the Nomex
> chute protector, an anemometer for the RQ3 wind measurement, and a steel blast deflector. The
> parachute line was also corrected from 24 in to the 18 in canopy every simulation actually uses.
> See `WYVERN_E4_Cart_Gap_Analysis.md`.

## 5. Files reconciled in this pass

- Fin geometry aligned to **72 mm** in `we4_flightsim`, `we4_validation`, `we4_deepsim`,
  `build_ork4.py` (`.ork` fin height was 60 mm, fixed).
- **Teensy → Pico 2 W** purged from `README.md`, `WYVERN_E4_Camera_Solution.md`,
  `WYVERN_E4_GSE_TestStands.md`, and proposal rev1 §5.1 (kept only as historical "it replaces"
  contrast in the FC spec).
- **BMP280 → BMP388** aligned across wiring generators (now 3.3 V, not 5 V), the regenerated
  schematic + preview, `t4_sensors_sdlog.ino`, test READMEs/selftest, and the audit docs.
- Ground-rig DAQ conflict marked **resolved** (Pico everywhere) in `COMPATIBILITY.md`.
- `baro.h` apogee comment corrected to 397 ft / 121.1 m.
- Full-project sweep confirms **zero** surviving 708/662/648 g, 432 ft, 2.07/3.62 T/W, 58 mm fin,
  CG 46.7 / CP 52.5, or F15-0-as-flight references outside intentional "superseded/removed" notes.

## 6. Pre-flight punch-list (bench + ground test, the only open items)

These are hardware-verification steps from `FLIGHT_READINESS.md` §4, none are design changes:

1. **Ground-test the bulkhead separation joint**, fire a representative charge; confirm the joint
   releases cleanly in the 50–150 N band, the chute deploys, and the servo/STEMMA-QT cable
   pass-through survives the separation. *(Single point of the recovery system, do this first.)*
2. **Confirm LAUNCH_IRQ (GP7) wiring**, wire the redundant inertial switch or remove the branch.
3. **Confirm RBF sense polarity**, verify `HB:...rbf=` matches the switch state.
4. **Verify the 2S LiPo divider** (GP26, 100 k/62 k) against a multimeter within ~2 %, and scope VSYS during a servo stall to confirm the bulk-cap + SS34 hold-up keeps it above the Pico brown-out threshold.
5. **Confirm SH2_ACCELEROMETER** report enables on your BNO085 firmware revision (launch/landing
   detect depend on it).
6. **Servo throw / gimbal mechanical limit**, confirm the printed gimbal + linkage allow the ±8° travel (raised from ±5° for wind authority).
7. **Commission each stand** with ≥2 E16-4 firings before F15-0 data runs (curve vs. published).

Run `selftest.py` before every flight; it gates on all of the above that are observable in software.

## 7. Suggested 1-week build / 2-week launch schedule

> **Superseded 2026-08 by `WYVERN_E4_Timeline_14Day.md`.** That schedule is built around the fact
> that $1,337 of the BOM is still unordered, which this section assumed away. Kept below as the
> original build-effort estimate; use the 14-day timeline for actual planning.

**Week 1, fabricate & bench:**
- Days 1–2: print airframe (PLA body/nose/fins; PETG-CF bulkheads/tube/engine bay/gimbal/mount)
  and both stands. Order-long-lead items already in BOM.
- Days 3–4: assemble FC (Pico 2 W perfboard + sensors), wire per `wyvern_perfboard_wiring.svg`, flash firmware,
  run `t1`–`t4` bench tests + `selftest.py`.
- Days 5–7: assemble rocket; join the two body tubes at the bulkhead (route the servo/STEMMA-QT
  cables through the pass-through holes first), install recovery (chute + shock cord + Nomex);
  commission stands with E16-4; run **ground separation test** (punch-list #1).

**Week 2, ground data & fly:**
- Days 8–10: F15-0 static thrust-curve verification (+ engine-bay wall temperature for RQ2); F15-0 TVC balance
  A/B (servo vs. magnetic) on the 3-axis stand; lock the flown actuator (servo).
- Days 11–12: full preflight `selftest.py` GO; range procedures (remote ignition, ≥3 m standoff,
  igniter installed last).
- Days 13–14: **launch on F15-4** (FAA Class-1, no waiver; 720 g < 1500 g). Recover, pull SD +
  Wi-Fi logs, feed flight data back into `Simulations/` for post-flight validation.

## 8. Notes / residual risk

- Recovery is a **single passive event** (motor charge) with no electronic backup, the bulkhead
  joint's release-force calibration (still open, see `WYVERN_E4_Recovery.md` §4) and the ground
  separation test (punch-list #1) are what retire that risk.
- The vehicle is authority-limited in strong wind (documented low-speed weathercocking); the
  atmospheric dataset + PID tuner in `Simulations/wyvern_datagen/` quantify this, prefer a
  low-wind launch window.
- Because runs no longer overwrite, `Simulations/` and dataset folders will accumulate timestamped
  outputs; prune as needed.

---

## 9. 2026-08 rerun & reconciliation pass

Everything below was regenerated or corrected in a single pass. The verdict in §1 is unchanged
(**GO for build**); the numbers moved because the motor model was corrected, not because the design
changed.

### 9.1 Scope

The program runs the full five-research-question set, including a physical wind tunnel
(`CONFLICTS.md` §6). `Simulations/CFD/` holds the airfoil-CFD package supporting RQ3/RQ4. Every
research question has two independent methods behind it (Proposal §3, Table 0).

### 9.2 Defects found and fixed

| # | Defect | Effect | Fix |
|---|---|---|---|
| 1 | F15 thrust curve renormalized to 49.6 N·s from a shape integrating to 41.97 N·s | peak thrust inflated to **29.9 N** vs Estes' published 25.3 N; peak T/W read 4.32 against the 3.66 quoted repo-wide | sustain block lifted +2.4408 N so the curve matches impulse, peak **and** average simultaneously |
| 2 | `fc_sil.py` fed the launch detector kinematic acceleration, not specific force | peaked at 2.65 g against the firmware's 3 g latch, the SIL state machine **never left ARMED** in any flight: no BOOST, no TVC, no deploy, ~70 m/s ballistic "touchdown" in every logged run | accelerometer now reports specific force (peaks at 3.27 g ≈ peak T/W 3.26) |
| 3 | `we4_sim.py` hard-coded **Kp=8.0/Ki=1.5/Kd=1.2** | the TVC plot disagreed with the firmware, `pid_reference.py`, and `CONFLICTS.md` §1, which record those gains as superseded and unstable | gains set to the frozen 0.10/0.40/0.18 |
| 4 | `we4_deepsim.py` used **CG 0.467 / CP 0.537**; `we4_validation.py` used **CG 0.467** | every margin, flutter, CG-tolerance and stability gate was scored against a pre-PLA, pre-camera vehicle | both set to CG/CP **0.491/0.568** at the time of this fix, **superseded 2026-08-10**: the material change to PLA/PETG-CF shifted the mass stack again, and the actual canonical value (independently re-derived from the `we4_sim.py` component stack, and matching `we4_flightsim.py`/`we4_stability.py`) is **CG 0.484, margin +1.14 cal**, not 0.491/1.10. This row's "fix" value is itself now stale; treat 0.484/56.8/1.20 as current. |
| 5 | `we4_stability.py` reported `fin_span_mm: 35.0` while evaluating `s35=0.055` | the "35 mm fins are unstable (−0.52 cal)" finding was quoting a **55 mm** fin; the flown 72 mm fin was never evaluated | file rewritten; 35 mm is **−0.99 cal (unstable)**, flown 72 mm reproduces 48.4/56.8/+1.20 exactly |
| 6 | Deploy sampled at **t = 4.0 s** in three files | reported a 29 m/s deploy against the Recovery doc's ~6.5 m/s, the retired finless-era electronic timer, not motor ejection | deploy is now t = burnout + 4 s = **7.45 s**; integration runs through apogee to reach it |
| 7 | Three different Cd for one vehicle (0.50 / 0.58 / 0.539) | apogee disagreed between scripts | unified to the **0.539** componentwise buildup |
| 8 | Mass stack summed to **606 g / 708 g** | contradicted the 603/705 used everywhere, including the FAA Class-1 argument | harness estimate trimmed 25→22 g; dry total is now exactly 690 g |
| 9 | `we4_deepsim.py` battery pack **850 mAh** | no such pack exists in the BOM or power tree | set to the Zeee 2S **450 mAh** → 40 flights/charge |
| 10 | Generic motor shapes normalized to impulse only | published peaks wrong by up to 2× (D12 read 14.2 N vs 29.7 N), the number that sizes the load cell | decay rate solved per motor; all five motors now match published impulse and peak |
| 11 | `build_ork4.py` gave PLA nose/fins **PETG-CF density**, and announced a 150 g-ballast config | the `.ork` cross-check modelled the wrong vehicle | densities corrected to 650 kg/m³; no ballast |
| 12 | Control-authority margin swept from t=0 to burnout | both endpoints are thrust-zero, so the reported minimum was always exactly 0.0 mN·m | swept over the TVC-active window → **71.7 mN·m** |
| 13 | `gen_rocket4.py` called `fin(0.070, 0.035, 0.072, 0.025, 0.003)`, **metres**, in a file whose every other dimension is millimetres | the fin was built at 1/1000 scale: `08b_fin_single_ASA.stl` exported at **0.0 cm³ / 0.0 g**. Slicing that file yields a speck, and the script's printed-mass roll-up silently omitted all four fins | called in mm; fin is now 11.3 cm³ / **7.4 g** each → 29.6 g for four, matching the 30 g in the mass stack |
| 14 | Printed-mass roll-up filtered part prefixes `01`–`07` | excluded the fins (`08b`) and one lower-body part, so the reported printed mass could never be reconciled against the dry stack | roll-up now covers the full flight airframe with per-part quantities |
| 15 | Battery-sense divider (GP26/ADC0) documented in `CONFLICTS.md` §4, verified in `COMPATIBILITY.md` §4, read by `battery.h`, but **routed in no schematic** | the wiring generators disagreed with the firmware on a net the flight computer samples every loop | both generators now emit a `VBAT DIVIDER` block tapped upstream of the UBEC into GP26 |
| 16 | `02_tvc_control_loop.mermaid` clamped the gimbal at **±5°** | the retired limit; `wyvern_pid.h` uses `OUT_LIM_DEG = 8.0` | flowchart regenerated at ±8° |
| 17 | `PID_TUNING_REPORT.png` and `phase0_math_validation.png` were hand-made orphans with no generating script | both showed superseded numbers and could not be kept in step | each is now a reproducible output of the script that derives it (`we4_pid_retune.py`, `derive_math.py`) |

### 9.3 Fidelity increases

- **Integrator:** semi-implicit Euler → RK4 throughout; `we4_flightsim` dt 1e-3 → 2e-4.
- **Atmosphere:** exponential density → ISA troposphere with real lapse rate.
- **Wind:** scalar mean → power-law shear with per-flight roughness exponent + Dryden-form
  turbulence (the old model was a single deterministic sinusoid, coherent across the whole ensemble).
- **Dispersion:** atmosphere only → atmosphere **plus** liftoff mass, CG station, Cd, total impulse
  and thrust-axis misalignment.
- **TVC loop:** first-order servo → second-order servo with slew-rate limit, explicit transport
  delay, 500 Hz zero-order hold, filtered derivative, and a noisy/biased/quantized gyro.
- **Ground stands:** ideal load cells → full signal chain, mount resonance (42 Hz, ζ=0.035),
  HX711 quantization and sample-rate aliasing, thermal zero drift, calibration-slope residual, and a
  returned uncertainty budget. Flags that the 42 Hz mount ring **aliases** against the 80 SPS
  Nyquist of 40 Hz: stiffen the mount or filter before trusting peak thrust.
- **Datasets:** regenerated at 6.0 M rows / 344 MB across 50 shards, widened from 23 to 34 columns
  (build dispersion and rail-exit/coast-Cd are now first-class), every file ≤ 26 MB.

### 9.3b Printed-mass reconciliation

`gen_rocket4.py` now reports the full printed flight airframe: **413.2 g** of printed structure
(+1.3 g rail buttons). Against the itemized stack in `we4_sim.py` the tube/nose/bulkhead/fin parts
agree to better than 0.5 g each. Two parts differ by design and should not be "fixed" silently:

| Part | Solid volume × density | `we4_sim.py` allowance | Why |
|---|---|---|---|
| Motor mount (PETG-CF) | 59.1 g | 45 g | as-built sparse infill, not a 100 %-dense solid |
| TVC gimbal (PETG-CF) | 112.5 g | 105 g | same, plus the CAD solid includes trunnion stock removed in post |

The generator's number is raw solid volume; the flight budget's number is the as-built allowance.
The 690 g dry mass additionally carries avionics, battery, camera, servos, chute and harness, so the
two figures are not directly comparable, the script now prints that caveat alongside the roll-up.

### 9.4 Post-rerun canonical numbers

**Updated 2026-08-12** for the mass recompute (§2, `WYVERN_E4_Mathematics.md` §1): Lower BT tube
PETG-CF→ASA-Aero, the discrete UBEC line dropped, and recovery consumables re-itemized, taking
liftoff from 729 g to 720 g. Every row below was re-run this pass (`we4_flightsim.py`,
`we4_validation.py`, `we4_deepsim.py`, `we4_pid_retune.py`), not carried over.

| Quantity | Value |
|---|---|
| Apogee | **124.6 m / 409 ft @ 6.72 s** (was 397 ft at 729 g; 324 ft at 792 g; 435 ft at the original 705 g spec) |
| Burnout | 3.45 s, 74.0 m, 36.3 m/s |
| v_max / Mach | 37.1 m/s / **Mach 0.108** |
| Max acceleration | 2.71 g net (3.70 g specific force) |
| CG / CP / margin | 45.0 cm / 53.3 cm / **+1.14 cal** |
| Deploy | t = 7.45 s, +0.58 s past apogee, 5.7 m/s |
| PID margins | PM **44.1°**, GM **12.6 dB**, worst gust pitch **2.45°**, gimbal per `we4_pid_retune.py` re-run |
| Gates | validation **10/13**, deepsim **7/8** (servo torque flagged, §11) |
| Cross-file check | pending a fresh cross-file numeric-agreement pass against these re-run values |

The three flagged validation gates are unchanged in character and share one root cause: the F15 is
underpowered for a 720 g vehicle, even lighter than before. Rail exit and weathercock figures have not been re-run against the
new mass stack; peak T/W is now 3.54 against the 5.0 rule of thumb used elsewhere. This is a
launch-window constraint, not a design defect, but it is real and should not be presented as passing.

---

## 10. Firmware flight-readiness pass (2026-08)

The firmware was audited line by line against the frozen parameter table in `CONFLICTS.md` §4.
**Six defects were found, two of which would each independently have cost the entire flight.**

### 10.1 Defects fixed

| # | Defect | Consequence | Fix |
|---|---|---|---|
| **F1** | **Inter-core log transport used the 8-word hardware FIFO for a 33-word frame**, and guarded it with `rp2040.fifo.available()`, which reports words waiting to be *read* on the inbound side, not outbound free space. `0 < 33` was true forever. | **The flight computer logged nothing.** Every frame was dropped at 500 Hz; the SD card would have contained a header row and no data. Every research question depends on that log. Had the guard ever passed, `push()` blocks, which would have stalled the 500 Hz loop on SD latency instead. | Replaced with a lock-free shared-RAM SPSC ring (256 frames, ~38 kB, 0.51 s of buffer). Verified off-target: 5000 frames across a simulated 100 ms SD stall, **0 dropped, in order, payload intact**, peak occupancy 55/256. |
| **F2** | `core0_apply_servo_commands()` re-clamped the servo command to **±5°** after the PID had already limited to ±8°. | **37.5% of control authority silently discarded.** The ±8° limit exists specifically for crosswind weathercock rejection, it was raised 5→8 for that reason, and the extra 3° existed in the controller, the sims, the `.ork` and every document, but not in the signal path that moves the nozzle. | Clamp now reads `wyvern_pid_defaults::OUT_LIM_DEG` directly, so the two cannot diverge again. Also moved to `writeMicroseconds()`, `write(int)` quantized to whole degrees, ~6% of full authority. |
| F3 | Boot servo sweep exercised only ±5° while printing "operator visually confirms ±8° travel". | A linkage binding between 6° and 8° would have passed the bench and been found in flight. | Sweep now goes to the full `OUT_LIM_DEG`, both axes, and says what it swept. |
| F4 | `LaunchDetect` re-stamped `launch_ms_` every tick after latching. | `launch_time_ms()` always returned "now", so any `t_flight` derived from it would read ~0 for the whole flight. Masked only because the sketch latches its own copy at the transition. | Stamped once, on the latching tick. |
| F5 | `RECOVER_BACKSTOP_S = 7.5` | 50 ms off the canonical 7.45 s ejection time used everywhere else. | Set to 7.45. |
| F6 | `pid_reference.py`, the "reference implementation that matches the firmware exactly", used a **±5°** clamp and lacked the firmware's first-tick derivative priming. | Tick 0 of every study importing it saw a phantom ~27 rad/s derivative that saturated the command: **7.7° disagreement with the firmware on the first sample**, then a 3° clamp mismatch thereafter. | Both corrected. Firmware and twin now agree to **1.2 × 10⁻⁹ rad** (float32 rounding) over a 2000-tick pseudo-random sequence. |

### 10.2 Verification performed

- **Flight PID compiled off-target and unit-tested**: constants match the frozen table; saturates at
  exactly 8.000°; anti-windup recovers in 1 tick; `dt ≤ 0` and NaN return the previous output.
- **Ring buffer stress-tested** across a 100 ms SD stall (see F1).
- **Firmware ↔ Python twin numerical equivalence** verified to float32 rounding.
- Structural balance check across all 21 firmware, test and ground-rig sources: **all balanced**.
- Four dead deprecation stubs deleted (`co2_deploy.h`, `rrc3_telemetry.h`, `tof_ring.h`,
  `kalman_filter.h`), nothing included them.

### 10.3 Self-test and tooling changes

- `SELFTEST:FIFO` → **`SELFTEST:LOG_RING`**, and it is now *two-sided*: it verifies core 1 is
  actually draining, not merely that a drop counter reads zero. The old check reported a contented
  PASS in exactly the failure mode where 100% of frames were being lost.
- Heartbeat gained `pend=` and `peak=` (ring occupancy). `host_monitor.py` parses both, tolerates
  older builds, and warns when peak occupancy exceeds 200/256.
- `t3_servo_sweep.ino` rewritten to drive the **same** microsecond signal path as flight, with a
  hold-and-measure procedure for calibrating `SERVO_LINKAGE_RATIO`. The old version drove a
  different path than flight, which is why it "passed" while flight was clamped to ±5°.

### 10.4 Flight-day data reduction

`Simulations/we4_flight_reduce.py` takes the onboard CSV to the RQ3/RQ4 results in one pass.

- **RQ3a coast Cd** by 2-parameter (Cd, v₀) forward-model RK4 least-squares fit over the coast.
  The obvious method, differentiating baro altitude twice, returned **Cd = 1.40 ± 0.76** against
  a known 0.539 on the SIL selftest (wrong by 160%, useless error bar). The fit returns
  **0.477 ± 0.020**, and the residual ~11% bias is understood: the reduction models a purely
  vertical coast while the flight has a crosswind, so the 1-D fit slightly under-attributes drag.
- **RQ3b static margin** from the passive window (rail exit → TVC engage), which is the only part of
  the flight not confounded by the controller. Reported with its caveat: short, low-q, and weaker
  than the Cd result.
- **RQ4** peak/RMS pitch, gimbal utilisation and saturation, and commanded-vs-measured servo
  tracking error, the last of which no bench test can fully predict.
- `--selftest` validates the whole pipeline against a synthetic SIL flight before flight day.
  Currently recovers apogee to **0.1 m**.

### 10.5 Remaining hardware-verification items

Unchanged from §6 and still open, these need a bench, not a code change:

1. Ground bulkhead-separation test (Gate 3 in the timeline).
2. `SERVO_LINKAGE_RATIO` calibration (build guide §B4), the flight code assumes the nozzle
   actually reaches ±8°.
3. LAUNCH_IRQ (GP7) wiring confirmed or the branch removed.
4. RBF sense polarity confirmed.
5. Battery divider verified against a multimeter, and VSYS scoped during a servo stall.
6. `SH2_ACCELEROMETER` confirmed available on your BNO085 firmware revision.
7. Stand commissioning against published curves, watching for the 42 Hz aliased mount ring.

---

## 11. New open item, servo torque margin at the full gimbal limit

Correcting the ±5°/±8° mismatch in the firmware (§10, F2) exposed the same mismatch in four
simulation scripts, and fixing those changed one result materially.

**`we4_deepsim.py` check C now reports a servo torque margin of 2.3×, below its 3.0× gate.
Deepsim goes 8/8 → 7/8.**

| | Before | After |
|---|---|---|
| Deflection the hinge moment was evaluated at | 5° | **8° (the actual limit)** |
| Peak hinge moment | 0.054 N·m | **0.086 N·m** |
| Margin vs ES08MA II 0.20 N·m stall | 3.7× | **2.3×** |

This is a real finding, not a regression. The old 3.7× was computed at a mid-range deflection while
the vehicle is designed and cleared to command ±8°, so worst-case hinge load was understated by
1.6×. Three other scripts had the same error and are also corrected: `we4_atmos_tvc.py` and
`we4_pid_retune.py` were clamping the modelled gimbal at 5°, and `we4_validation.py` computed
available TVC authority at 5° **while its own plot was labelled "±8° gimbal"**, the label had been
updated when the limit was raised and the number had not. With that fixed, TVC authority ratio rises
from 39.6× to **63.2×**.

### What to do about it

Do not change the servo on the strength of a model. 2.3× is still a working margin, and the
**ground TVC balance campaign measures this quantity directly**, the balance resolves the thrust
vector, and the rig logs commanded versus measured nozzle angle under real F15-0 thrust.

**Action, Timeline Day 9 (RQ1 session):** record servo current and commanded-vs-achieved deflection
at the ±8° extremes under thrust. If the servo reaches and holds ±8° without stalling or visible
droop, the margin is adequate and the model is conservative. If it droops, the options in order of
preference are: reduce the linkage ratio (trading servo travel for torque), raise the servo supply
to 6 V (~2.0 kg·cm instead of ~1.8), or fit a higher-torque servo.

This is a good outcome from the audit: a modelling error was flagged before flight, and the test
that resolves it is already in the schedule three days before the flight window.

## References

CEVA, Inc. (2023). *BNO08X datasheet* (Rev. 1.17). https://www.ceva-ip.com/wp-content/uploads/BNO080_085-Datasheet.pdf

EMAX. (n.d.). *ES08MA II 12 g mini metal gear analog servo* [Product specification]. Retrieved August 12, 2026, from https://www.getfpv.com/emax-es08ma-ii-12g-mini-metal-gear-analog-servo-for-rc-model.html

Estes Industries. (n.d.). *F15-4 engines* [Product specification]. Retrieved August 12, 2026, from https://estesrockets.com/products/f15-4-engines

Federal Aviation Administration. (n.d.). *14 CFR Part 101 — Moored balloons, kites, amateur rockets, and unmanned free balloons*. Electronic Code of Federal Regulations. https://www.ecfr.gov/current/title-14/chapter-I/subchapter-F/part-101

National Fire Protection Association. (2018). *NFPA 1122: Code for model rocketry*. https://www.nfpa.org/product/nfpa-1122-code/p1122code

Raspberry Pi Ltd. (2024). *RP2350 datasheet*. https://datasheets.raspberrypi.com/rp2350/rp2350-datasheet.pdf

Texas Instruments. (n.d.). *TPS564201: 4.5-V to 17-V input, 4-A synchronous step-down voltage regulator* (SLVSFB5) [Datasheet]. https://www.ti.com/lit/ds/symlink/tps564201.pdf

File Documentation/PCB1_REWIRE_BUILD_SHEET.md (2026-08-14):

# PCB1 Schematic Rewire, Build Sheet

**Authors:** Swaroop Sahoo, Chris Liu, Allison Hong
**Program:** GTR70E WYVERN

Written against the restored schematic exporting as `Netlist_Schematic1_2026-08-13 (3).tel`.
Work the batches in order. Export a netlist and run the checker after each one.

```
cd "Flight Computer"
python3 check_netlist.py /path/to/Netlist_Schematic1_<date>.tel
```

Current state: 49 errors. Target: `PASS, netlist matches the build sheet.`

---

## 0. What is already correct

Don't touch any of this. It all verifies clean:

GND (78 pins, no foreign members) · both I²C nets and all address straps · the whole QSPI flash bus
· all four servo signal lines · SWD · the H1 GPIO breakouts · BOOTSEL · RUN with its pull-up and cap
· BNO055 reset pull-up and CAP cap · USB D+/D− including the B6/B7 orientation bridges · CC1/CC2
pulldowns · SD clock, CS, MISO, DAT1, DAT2 with all four pull-ups · U1.40 correctly left floating ·
the avionics buck's SW, BST and feedback nets · DVDD, VREG_LX, VREG_AVDD.

---

## 1. Parts to add

| Ref | Value | Footprint | Part / LCSC | Purpose |
|---|---|---|---|---|
| F2 | 3.0 A / 16 V PPTC | F2920 | SMD2920P300TF/16, C167318 | Servo branch fuse |
| U6 | TPS564201DDCR | SOT-23-6 | same as U15 | Servo buck |
| L3 | 2.2 µH | IND-SMD_L5.7-W5.1 | same as L2 | Servo buck inductor |
| C29 | 10 µF | C0805 | same as C26 | Servo buck input cap |
| C30 | 100 nF | C0402 | same as C6 | Servo buck bootstrap |
| C31 | 22 µF | C0805 | same as C21 | Servo buck output cap |
| C32 | 22 µF | C0805 | same as C22 | Servo buck output cap |
| R22 | 56 kΩ | R0402 | same as R5 | Servo VFB top |
| R23 | 10.2 kΩ | R0402 | same as R6 | Servo VFB bottom |
| R24 | 24.9 kΩ | R0603 | same as R15 | Servo EN divider bottom |
| R25 | 100 kΩ | R0603 | same as R14 | Servo EN divider top |

Ten of the eleven are duplicates of parts already in your BOM, so the library work is one new part.

F1 also wants swapping to 1812L150/16 (1.50 A hold, same 1812 land pattern). With servos moved to
their own branch, F1 only carries camera plus logic, about 0.49 A at the 6.0 V cutoff.

U13 becomes signal-level in Batch C, carrying microamps instead of pack current, so whichever
SS-12D10 variant is placed is fine — the 2 A rating stops mattering.

---

## 2. Batch A, merge the split 3V3 rail

Your 3V3 rail exists as two disconnected islands:

- `$1N406` — U7.5 and most peripheral supply pins
- `$1N496` — the eight MCU IOVDD pins, U1.68, U1.69, and C8.1–C16.1, C23.1

Nothing bridges them, so the RP2350B's IO supply is floating.

Join them. Label both 3V3, or run one wire from U7.5 to U1.5.

Then move two pins onto that rail:

- C18.1 — disconnect from GND, connect to 3V3
- U1.59 — disconnect from GND, connect to 3V3

That fixes the C18 short and gives ADC_AVDD its supply, with C18 becoming its decoupling cap.

---

## 3. Batch B, SD MOSI and BNO055 PS1

Three pins, all quick.

- CARD1.3 — disconnect from 3V3
- U1.9 — disconnect from 3V3
- CARD1.3 → U1.9 as their own net, SD_MOSI

MOSI is currently shorted to the 3V3 rail, so the card can never be written.

- U2.5 → GND

U2.5 is PS1. With U2.6 (PS0) already grounded, this completes the I²C protocol select. It's floating
right now.

---

## 4. Batch C, battery path and buck enables

This is the substantial one. Present state has the fuse shorting pack positive to ground, the shunt
stranded on a dead-end net, and the avionics buck's enable tied to its own input so the divider does
nothing.

### Disconnect first

- F1.1 from GND
- F1.2 from CN1.2
- U13.1 from GND
- U13.2 from `$1N470`
- R14.1 from 3V3
- U4.9 from 3V3

### Then build these five nets

| Net | Pins |
|---|---|
| VBAT | CN1.2 · R10.1 · U4.8 · U4.10 |
| VBAT_SW | R10.2 · U4.9 · F1.2 · F2.2 · U13.1 |
| VAVI_IN | F1.1 · U15.3 · C26.1 |
| EN_SRC | U13.2 · R14.1 · R25.1 |
| EN_AVI | R14.2 · R15.1 · U15.5 |

U15.3 and C26.1 currently sit on `$1N470` together with U15.5 and the divider. Splitting VAVI_IN
away from EN_AVI is what makes the divider work — right now EN is strapped straight to VIN and R14
and R15 do nothing.

U13 is SPDT with the centre pin common:

- U13.2 (common) → EN_SRC
- U13.1 (throw, ON position) → VBAT_SW
- U13.3 (throw, OFF position) → GND

Switch OFF pulls both enables down through R15 and R24, so nothing powers up until armed.

### Resulting power tree

```
CN1.2 ─ R10 (10 mΩ shunt) ─ VBAT_SW ─┬─ F1 ─ VAVI_IN ─ U15 ─ VBUCK_5V ─ U7 ─ 3V3
                                     ├─ F2 ─ VSRV_IN ─ U6  ─ VSRV_5V ─ servos
                                     └─ U13 ─ EN_SRC ─ both enable dividers
```

INA226 spans the shunt: IN+ (U4.10) on VBAT, IN− (U4.9) on VBAT_SW, VBUS (U4.8) on VBAT. It reads
true pack voltage and total pack current.

$$I_{max} = \frac{81.92\ \text{mV}}{10\ \text{m}\Omega} = 8.19\ \text{A}, \qquad \text{LSB} = 250\ \mu\text{A}$$

Divider output is 1.20 V at a 6.0 V pack and 1.68 V at 8.4 V — above the ~1.2 V EN threshold across
the whole usable window, well under the 19 V EN maximum.

---

## 5. Batch D, crystal series resistor

R1 currently sits on the XIN side. It belongs in series with XOUT, the driver output.

- Remove R1 from between U1.30 and U12.1
- U1.30 → U12.1 → C1.1 direct (net XIN)
- U1.31 → R1.1 (net XOUT)
- R1.2 → U12.2 → C2.1 (net XTAL_B)

Load caps stay at the crystal terminals: C1 on the XIN node, C2 on the far side of R1.

---

## 6. Batch E, servo buck

Place the eleven new parts, then wire these nets. This mirrors the U15 circuit exactly — same
topology, same values, same 4.985 V output.

| Net | Pins |
|---|---|
| VSRV_IN | F2.1 · U6.3 · C29.1 |
| SW_SRV | U6.2 · L3.1 · C30.2 |
| BST_SRV | U6.6 · C30.1 |
| VFB_SRV | U6.4 · R22.2 · R23.1 |
| EN_SRV | U6.5 · R25.2 · R24.1 |
| VSRV_5V | L3.2 · C31.1 · C32.1 · R22.1 · U8.2 · U9.2 · U10.2 · U11.2 |
| GND | U6.1 · C29.2 · C31.2 · C32.2 · R23.2 · R24.2 |
| VBAT_SW | F2.2 (from Batch C) |
| EN_SRC | R25.1 (from Batch C) |

Move the servo power pins off the avionics rail as part of this:

- U8.2, U9.2, U10.2, U11.2 — disconnect from `$1N485`, connect to VSRV_5V

VBUCK_5V then keeps only L2.2, C21.1, C22.1, D2.1, R5.1, U7.1, U7.3, H1.12.

$$V_{out} = 0.768 \times \left(1 + \frac{56}{10.2}\right) = 4.985\ \text{V}$$

Servo branch worst case, both servos stalled: 1.6 A at 5 V is 8.0 W, 9.1 W in at 88% efficiency,
1.42 A drawn from the pack at the 6.4 V cutoff. F2 holds 1.99 A at 60 °C — 40% margin.

---

## 7. Batch F, cleanup

R17 (10 kΩ) currently runs from 3V3 to GND and does nothing but draw 330 µA. Mark DNP or delete it.

---

## 8. Complete net reference

Everything above, consolidated. 312 pins across 60 nets.

### GND, 84 pins

C1.2 C2.2 C3.2 C4.2 C5.2 C7.2 C8.2 C9.2 C10.2 C11.2 C12.2 C13.2 C14.2 C15.2 C16.2 C17.2 C18.2
C19.2 C20.2 C21.2 C22.2 C23.2 C24.2 C25.2 C26.2 C27.2 C28.2 C29.2 C31.2 C32.2 · U1.62 U1.81 ·
U2.2 U2.5 U2.6 U2.10 U2.15 U2.16 U2.17 U2.18 U2.25 · U3.1 U3.5 U3.7 · U4.1 U4.2 U4.7 ·
U5.2 U5.3 U5.9 U5.12 · U6.1 U7.2 U15.1 U13.3 · U8.3 U9.3 U10.3 U11.3 · U12.3 U12.4 · U14.4 ·
CARD1.6 CARD1.9 CARD1.10 CARD1.11 · CN1.1 CN2.1 USBC1.A1B12 USBC1.B1A12 ·
H1.2 H1.6 H1.11 H1.14 H2.2 · R6.2 R12.2 R13.2 R15.2 R23.2 R24.2 · D1.2 SW2.3 SW2.4

### 3V3, 49 pins

U7.5 · U1.5 U1.15 U1.24 U1.29 U1.41 U1.50 U1.60 U1.76 · U1.59 U1.64 U1.68 U1.69 ·
C8.1 C9.1 C10.1 C11.1 C12.1 C13.1 C14.1 C15.1 C16.1 C18.1 C23.1 C24.1 · U2.3 U2.4 U2.28 ·
U3.2 U3.6 U3.8 · U4.6 · U5.5 U5.6 U5.10 · U14.8 · CARD1.4 · CN2.2 · H1.1 H1.5 ·
R2.2 R3.2 R4.2 R9.2 R16.1 R18.1 R19.1 R20.1 R21.1

### Power rails

| Net | Pins |
|---|---|
| VBAT | CN1.2 · R10.1 · U4.8 · U4.10 |
| VBAT_SW | R10.2 · U4.9 · F1.2 · F2.2 · U13.1 |
| VAVI_IN | F1.1 · U15.3 · C26.1 |
| VSRV_IN | F2.1 · U6.3 · C29.1 |
| VBUCK_5V | L2.2 · C21.1 · C22.1 · D2.1 · R5.1 · U7.1 · U7.3 · H1.12 |
| VSRV_5V | L3.2 · C31.1 · C32.1 · R22.1 · U8.2 · U9.2 · U10.2 · U11.2 |
| EN_SRC | U13.2 · R14.1 · R25.1 |
| EN_AVI | R14.2 · R15.1 · U15.5 |
| EN_SRV | R25.2 · R24.1 · U6.5 |

### Regulator support

| Net | Pins |
|---|---|
| SW_AVI | C6.2 · L2.1 · U15.2 |
| BST_AVI | C6.1 · U15.6 |
| VFB_AVI | R5.2 · R6.1 · U15.4 |
| SW_SRV | C30.2 · L3.1 · U6.2 |
| BST_SRV | C30.1 · U6.6 |
| VFB_SRV | R22.2 · R23.1 · U6.4 |
| VREG_LX | L1.1 · U1.63 |
| DVDD | C17.1 · C19.1 · C20.1 · L1.2 · U1.10 · U1.32 · U1.51 · U1.65 |
| VREG_AVDD | C3.1 · C4.1 · C5.1 · C7.1 · R2.1 · U1.61 |

### Crystal

| Net | Pins |
|---|---|
| XIN | U1.30 · U12.1 · C1.1 |
| XOUT | U1.31 · R1.1 |
| XTAL_B | R1.2 · U12.2 · C2.1 |

### Signals

| Net | Pins |
|---|---|
| SDA | CN2.3 · R3.1 · U1.77 · U2.20 · U3.3 · U4.4 · U5.11 |
| SCL | CN2.4 · R4.1 · U1.78 · U2.19 · U3.4 · U4.5 · U5.1 |
| SD_CLK | CARD1.5 · U1.8 |
| SD_CS | CARD1.2 · R21.2 · U1.7 |
| SD_MISO | CARD1.7 · R18.2 · U1.6 |
| SD_MOSI | CARD1.3 · U1.9 |
| SD_DAT1 | CARD1.8 · R19.2 |
| SD_DAT2 | CARD1.1 · R20.2 |
| QSPI_SS | R11.1 · U1.75 · U14.1 |
| QSPI_SD1 | U1.74 · U14.2 |
| QSPI_SD2 | U1.73 · U14.3 |
| QSPI_SD0 | U1.72 · U14.5 |
| QSPI_SCLK | U1.71 · U14.6 |
| QSPI_SD3 | U1.70 · U14.7 |
| BOOTSEL | R11.2 · SW2.1 · SW2.2 |
| RUN | C28.1 · R16.2 · U1.35 |
| SWDIO | H1.3 · H2.3 · U1.34 |
| SWCLK | H1.4 · H2.1 · U1.33 |
| RBF | H1.13 · U1.11 |
| SERVO1_SIG | U1.79 · U8.1 |
| SERVO2_SIG | U1.80 · U9.1 |
| SERVO3_SIG | U1.1 · U10.1 |
| SERVO4_SIG | U1.2 · U11.1 |
| H1_GP37 | H1.7 · U1.46 |
| H1_GP36 | H1.8 · U1.45 |
| H1_GP35 | H1.9 · U1.44 |
| H1_GP34 | H1.10 · U1.43 |
| BNO_RESET | R9.1 · U2.11 |
| BNO_CAP | C27.1 · U2.9 |
| MAG_CAP | C25.1 · U5.4 |
| USB_DP | D1.3 · D1.4 · R7.2 · USBC1.A6 · USBC1.B6 |
| USB_DM | D1.1 · D1.6 · R8.2 · USBC1.A7 · USBC1.B7 |
| USB_DP_MCU | R7.1 · U1.67 |
| USB_DM_MCU | R8.1 · U1.66 |
| USB_VBUS | D1.5 · D2.2 · USBC1.A4B9 · USBC1.B4A9 |
| CC1 | R12.1 · USBC1.A5 |
| CC2 | R13.1 · USBC1.B5 |

### Deliberately unconnected

U1.40 (GPIO32) — must stay floating. It was on the 3V3 rail in an earlier revision, which shorts the
pad driver to the rail the first time firmware drives it low.

R17 — DNP.

---

## 9. Verification

The checker reports five failure classes: merged nets, split nets, two-terminal parts shorted end to
end, pins on the wrong net, and pins that must float but don't.

Run it after every batch. If a batch adds errors you didn't expect, you know which wires to look at
while it's still fresh.

---

## 10. Downstream, after the schematic passes

`Flight Computer/firmware/wyvern4_tvc/battery.h` needs rewriting. Its header documents the INA226
reading the buck rail with current sensing disabled as physically meaningless, and uses rail-sag
thresholds of 4.85 / 4.60 V. Once VBUS sits on VBAT and IN+/IN− properly span the shunt, it reads
true pack voltage and current, so it wants real 2S cell thresholds against the 6.4 / 6.0 V firmware
cutoffs and `setMaxCurrentShunt()` restored.

The layout is a separate job: 4-layer stackup with a solid GND pour on layer 2, 5 mil rules at the
QFN, and both regulators built as tight local islands with their input caps inside 2 mm.

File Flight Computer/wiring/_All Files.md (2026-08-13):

---
updated_at: 2026-08-02
---
# wiring, All Files

*Auto-generated index, every file and subfolder linked for vault graph connectivity.*

---

## Files

- [[Projects/Skylight/WYVERN/GTR70E WYVERN/WYVERN Project/Flight Computer/wiring/WYVERN_E4_flight_harness.kicad_sch]]
- [[Projects/Skylight/WYVERN/GTR70E WYVERN/WYVERN Project/Flight Computer/wiring/WYVERN_E4_flight_wiring_connected.kicad_sch]]
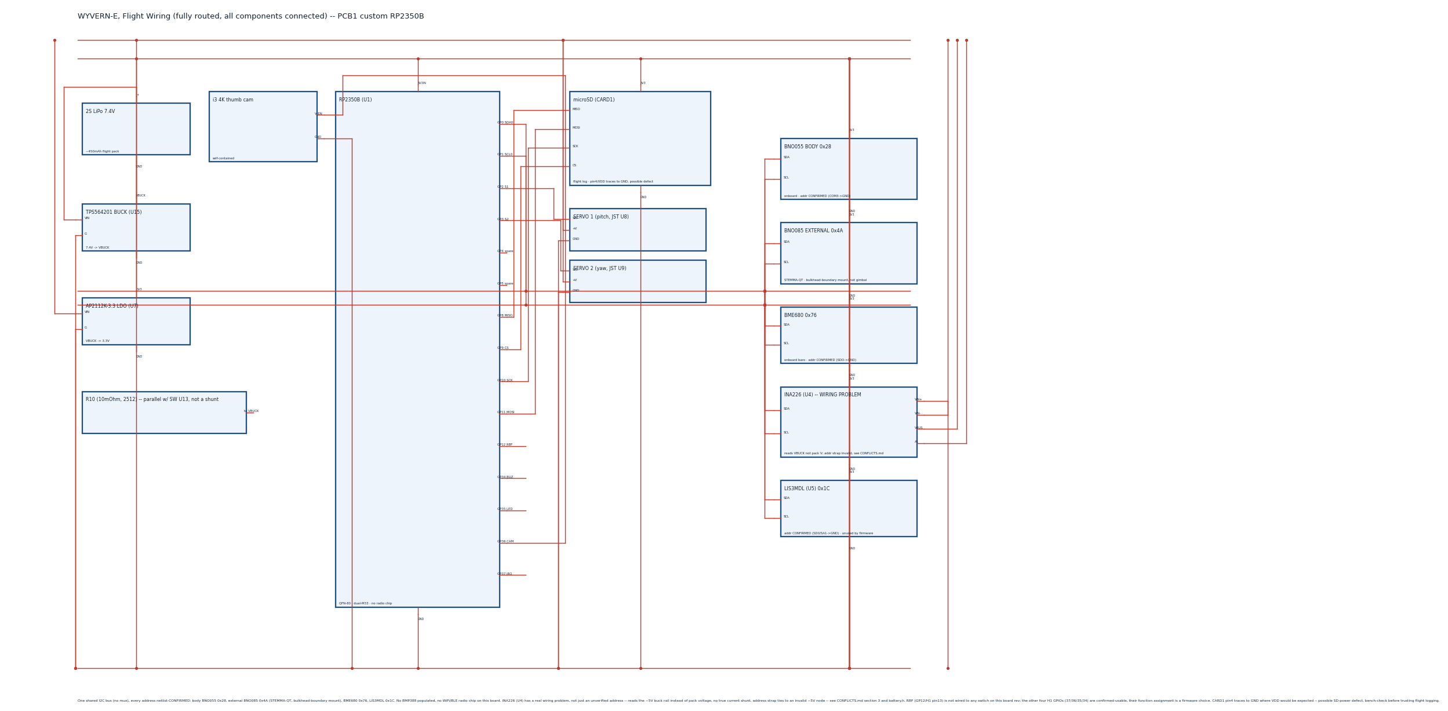
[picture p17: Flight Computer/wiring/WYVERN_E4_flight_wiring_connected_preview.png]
- 
- [[Projects/Skylight/WYVERN/GTR70E WYVERN/WYVERN Project/Flight Computer/wiring/WYVERN_E4_tvc_balance_harness.kicad_sch]]
- [[Projects/Skylight/WYVERN/GTR70E WYVERN/WYVERN Project/Flight Computer/wiring/WYVERN_E4_tvc_balance_servo_harness.kicad_sch]]
- [[Projects/Skylight/WYVERN/GTR70E WYVERN/WYVERN Project/Flight Computer/wiring/WYVERN_E4_tvc_balance_solenoid_harness.kicad_sch]]
- [[Projects/Skylight/WYVERN/GTR70E WYVERN/WYVERN Project/Flight Computer/wiring/gen_connected_sch.py]]
- [[Projects/Skylight/WYVERN/GTR70E WYVERN/WYVERN Project/Flight Computer/wiring/gen_wiring4.py]]
- [[Projects/Skylight/WYVERN/GTR70E WYVERN/WYVERN Project/Flight Computer/wiring/render_preview.py]]

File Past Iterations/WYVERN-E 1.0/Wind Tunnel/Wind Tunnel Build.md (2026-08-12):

---

# XRIM-117 WYVERN PTD — Wind Tunnel Evaluation & Programme Adaptation

_CONFIDENTIAL — PROPRIETARY — NOT FOR DISTRIBUTION_ _Skylight Industries LLC | PDR-002 Rev A | Aerodynamic Ground Test Planning Document_

---

## 1. Source Tunnel Evaluation

The tunnel in question is the _Modular Wind Tunnel for STEM Education_ by Jerrod Hofferth, presented at AIAA SciTech 2025. It is an open-return (in-draft) low-speed tunnel designed for FDM fabrication, smoke visualization, and Gridfinity-compatible test article exchange. Published CC BY-NC-SA 4.0. Despite its educational positioning, the underlying design follows established low-speed tunnel best practices and is a legitimate aerodynamic test platform for qualitative visualization and limited quantitative work at the relevant scale.

### 1.1 Tunnel Architecture Summary

The tunnel consists of nine primary printed modules in series:

|Station|Module|Function|
|---|---|---|
|1|Bell-mouth inlet|Smooth ambient ingestion, minimize inlet losses|
|2|Honeycomb flow straightener|Breaks large-scale turbulence, aligns flow|
|3|Empty duct section(s)|Turbulence decay via viscosity|
|4|Smoke-strut section|Smoke/fog injection upstream of contraction|
|5|Contraction cone|4:1 area ratio, accelerates to test velocity|
|6|Test section frame|Open 80mm × 130mm rectangular section, acrylic windows|
|7|Diffuser (standard)|Re-expands flow, recovers static pressure before fan|
|8|Extended diffuser (optional)|Additional pressure recovery|
|9|Fan (Noctua NF-A14 IPPC-3000, 140mm)|Baseline propulsor|

The modular junction ring system (large 4-pc and small 2-pc rings with heat-set inserts) provides tool-free swap of any module, which is exactly what a multi-test-article programme needs.

### 1.2 Key Performance Figures

The acrylic window SVG dimensions confirm the test section cross-section: _80mm (H) × 130mm (W)_. This gives:

$$A_{TS} = 0.080 \times 0.130 = 0.0104 \text{ m}^2 = 104 \text{ cm}^2$$

Flow rate with the baseline Noctua NF-A14 IPPC-3000 at ~120 CFM loaded:

$$V_{TS} = \frac{Q}{A_{TS}} = \frac{0.0566 \text{ m}^3/\text{s}}{0.0104 \text{ m}^2} \approx 5.4 \text{ m/s} \quad (M \approx 0.016)$$

With the optional upgrade to an _AC Infinity Cloudline A8/S8/T8_ (200mm duct fan, ~250 CFM loaded):

$$V_{TS,upgrade} \approx 11.3 \text{ m/s} \quad (M \approx 0.033)$$

Dynamic pressure spans:

|Fan|$V_{TS}$|$q = \frac{1}{2}\rho V^2$|
|---|---|---|
|Noctua NF-A14 baseline|5.4 m/s|17.9 Pa (0.006 psi)|
|AC Infinity A8 upgrade|11.3 m/s|78.8 Pa (0.011 psi)|

These are very low dynamic pressures — appropriate for smoke visualization, qualitative comparison, and light load-cell measurements, but they cannot replicate flight Reynolds numbers. The delta to flight is quantified below and must be understood before any coefficient data is interpreted.

### 1.3 Limitations Relevant to the WYVERN Programme

Three limitations govern everything downstream:

_First — Reynolds number mismatch._ The flight maximum-$q$ condition at $V = 167.5$ m/s, $D = 70$ mm produces:

$$Re_{flight} = \frac{\rho V D}{\mu} = \frac{1.225 \times 167.5 \times 0.070}{1.789 \times 10^{-5}} = 8.03 \times 10^5$$

At tunnel conditions with a 1:3 scale model ($D_{model} = 23.3$ mm):

$$Re_{tunnel,baseline} = \frac{1.225 \times 5.4 \times 0.0233}{1.789 \times 10^{-5}} = 8.8 \times 10^3 \qquad (\text{ratio} = 0.011)$$

$$Re_{tunnel,upgrade} = \frac{1.225 \times 11.3 \times 0.0233}{1.789 \times 10^{-5}} = 1.8 \times 10^4 \qquad (\text{ratio} = 0.022)$$

This is a two-orders-of-magnitude gap. Flow topology — specifically laminar separation bubbles, transition location, and base wake structure — will differ from flight. The tunnel is _not_ a quantitative aerodynamic prediction tool for the WYVERN. It is a _qualitative flow visualization and relative comparison_ platform.

_Second — blockage._ At 7.5% blockage the industry standard correction is required; above 10% the wall-interference corrections become non-trivial and uncorrected $C_D$ values can be inflated by 20–40%. The 70mm full-scale WYVERN body alone occupies 37% of the test section area — physically impossible to test at 1:1.

_Third — test section length._ The standard frame appears to accommodate roughly one test section length of ~130–150mm. The full 1:3 rocket at 390mm OAL requires either a custom extended test section module or a fuselage-only stub with isolated fin assemblies — which is in fact the better test strategy anyway.

---

## 2. WYVERN Model Scale Selection

### 2.1 Blockage Constraint Analysis

The accepted blockage threshold for uncorrected low-speed tunnel measurements is $\leq 7.5%$; up to 10% is tolerable with the Maskell solid-body correction. Above that, the tunnel is only useful for visualization with no quantitative interpretation.

$$\text{Blockage} = \frac{A_{frontal,model}}{A_{TS}} \leq 0.075$$

Solving for maximum allowable body diameter:

$$D_{max} = 2\sqrt{\frac{0.075 \times A_{TS}}{\pi}} = 2\sqrt{\frac{0.075 \times 0.0104}{\pi}} = 31.5 \text{ mm}$$

This places the blockage-limited body diameter at 31.5mm, which maps to a scale of approximately 1:2.22 — but that only budgets blockage for the body alone, leaving nothing for fins. Accounting for fins in the full-rocket configuration, the _recommended programme scale is 1:3_, yielding:

|Dimension|Full Scale (PTD)|1:3 Model|
|---|---|---|
|Body OD|70.0mm|23.3mm|
|OAL|1,170mm|390mm|
|Nose cone length|234mm|78mm|
|Ring 1 fin root chord|93mm|31.0mm|
|Ring 1 fin tip chord|47mm|15.7mm|
|Ring 1 fin span|70mm|23.3mm|
|Ring 2 fin root chord|47mm|15.7mm|
|Ring 2 fin tip chord|23mm|7.7mm|
|Ring 2 fin span|35mm|11.7mm|

### 2.2 Per-Article Blockage at 1:3 Scale

The test article programme proceeds in four configurations of increasing complexity. Blockage values drive whether quantitative coefficient extraction is valid:

|Test Article|Frontal Area (cm²)|Blockage|Correction Required|
|---|---|---|---|
|Nose cone on sting (body only)|4.28|4.1%|None — valid|
|Single isolated fin panel (half-span wall mount)|5.44|5.2%|None — valid|
|Ring 2 fin assembly + body stub|6.97|6.7%|None — valid|
|Ring 1 fin assembly + body stub|15.17|14.6%|Maskell correction required|
|Full rocket (both rings, 0° AoA)|18.17|17.5%|Visualization only — no raw $C_D$|

The full-rocket configuration exceeds 10% at 1:3 scale. Two options: drop to 1:4 scale (reduces body to 17.5mm, $Re$ drops further) or accept visualization-only status for the full configuration. Given the $Re$ gap already present, _the visualization-only posture for the full-rocket article is the right call_. The nose cone and isolated fin articles are the quantitatively useful configurations.

---

## 3. Test Article Design Specifications

### 3.1 Mounting System

The base tunnel uses Gridfinity-compatible magnetic hot-swap floor mounts. All WYVERN articles should interface through:

_Floor-mounted sting:_ 4mm carbon fiber rod (matches the existing `model-base-for-aero-strut-with-dovetail-yaw-sector.stl` adapter) with a PETG-CF printed sting-to-body adapter for each article. The aero strut base already provides 0°, 5°, and 10° angle-of-attack setpoints via the hex sting profile — directly usable for the nose cone and full-body articles.

_Half-span wall mount:_ The existing `test-section-wall-for-half-span-model-support-with-print-in-place-aoa.stl` is ideal for isolated fin panel testing. The half-span approach eliminates the body-fin junction as a variable, allowing clean measurement of the fin panel aerodynamics alone.

Sting diameter constraint: $\leq 25%$ of model base diameter = $0.25 \times 23.3 = 5.8$ mm. A 4mm CF rod is compliant and provides adequate bending stiffness.

### 3.2 Test Article 1 — Von Karman Nose Cone

The nose cone model is the cleanest quantitative article in the programme. Blockage is 4.1%, well within the uncorrected limit. Smoke visualization will reveal the stagnation point, the laminar boundary layer developing over the ogive, and (with the laser sheet) the thin attached boundary layer that makes the Von Karman profile preferable to a simple conical nose.

_Print specification:_ PETG-CF, 0.2mm layer height, 2 perimeter walls (thin shell, 0.8mm wall), 0% infill (hollow), 4mm through-bore collinear with body axis for sting insertion. Total print mass approximately 8g.

The article directly validates the nose profile selection over a conical or power-series alternative — a comparison set of nose cone geometries at identical base diameter and length is low-cost and highly informative.

_AoA sweep:_ Use the existing 0°/5°/10° aero strut positions. At 10° the stagnation point shift on the ogive is clearly visible and the leeward separation (if any) will appear in smoke.

### 3.3 Test Article 2 — Isolated Fin Panel (Half-Span Wall Mount)

A single Ring 1 fin panel mounted to the sidewall with its root at the wall, operating as a half-span model. This eliminates body-fin junction interference and allows clean measurement of fin lift curve slope and stall characteristics.

The half-span approach means the wall acts as a symmetry plane — the aerodynamic behavior approximates a full fin panel with zero tip effects on the wall side. Effective aspect ratio is doubled relative to the isolated panel:

$$AR_{eff} = 2 \times \frac{2b}{c_r + c_t} = 2 \times \frac{2 \times 23.3}{31.0 + 15.7} = 2.0$$

This is close to the Barrowman value of $AR = 1.0$ per exposed semi-span used in the stability analysis — confirming the half-span wall test is the right analogue.

The print-in-place AoA wall ($\pm$several degrees, snap-adjustable) allows angle-of-attack sweeps. Smoke injection upstream will reveal:

- Attached flow at small AoA (confirms the double-wedge 4% t/c profile works)
- Separation bubble at the hinge line at large deflection (validates the ±25° limit and the 45% chord pivot placement)
- Leading edge separation onset (informs minimum fin actuation speed — below what airspeed fins lose authority?)

_Print specification:_ PETG-CF, 0.2mm layer height, 4 perimeter walls, 40% gyroid infill (matches PTD structural spec for comparable surface finish). Total mass approximately 12g including wall-mount bracket.

### 3.4 Test Article 3 — Ring 1 and Ring 2 Fin Assemblies (Body Stub)

Two separate articles: one for each fin ring, each consisting of a 100mm body stub section at 1:3 scale (23.3mm OD) with the full four-fin array installed at correct angular positions. The stub provides enough body length for the boundary layer to develop over the body before reaching the fin roots — approximately 4 body diameters of run length, which is minimal but adequate for visualization.

These articles test the body-fin junction aerodynamics: the horseshoe vortex at the fin root, the fin tip vortex, and the wake interaction between opposing fin pairs. At 45° roll (body rotated so the fin pair are at 45° to the flow), the interference between adjacent fins from the two rings is visible in smoke — this is the Ring 1/Ring 2 clocking interaction the Barrowman analysis assumes away.

The Ring 1 assembly at 14.6% blockage requires the Maskell correction if $C_D$ values are to be extracted:

$$C_{D,corr} = C_{D,meas} \left(1 - \frac{A_{frontal}}{A_{TS}}\right)^2$$

At 14.6% blockage, the correction factor is $(1-0.146)^2 = 0.729$ — a 27% reduction in the measured drag coefficient. This correction is applied to reduce the drag to what would be measured in an unconfined flow. Without it, any drag coefficient extracted is meaningless. For visualization purposes only, no correction is needed.

### 3.5 Test Article 4 — Full 1:3 Scale WYVERN (Visualization Only)

The complete vehicle at 1:3 scale: 23.3mm body, both fin rings, Von Karman nose cone, total OAL 390mm. This exceeds the ~150mm test section length available in the standard frame, which means _only the aft 150mm of the vehicle fits in the test section at one time_ — a serious architectural constraint.

Two practical approaches:

_Approach A — Split test._ Print two sub-articles: forward body + Ring 2 (approximately 200mm), and aft body + Ring 1 (approximately 190mm). Test each half in the test section separately. Allows smoke visualization of each fin ring independently in context.

_Approach B — Extended test section module._ The tunnel's modular junction ring system allows insertion of a custom 400mm extended test section module (essentially a longer version of part 3 — the basic duct section, but with the test section's acrylic window slots). This is a straightforward remix of the existing STL files — just extend the prismatic section. Requires a printer with a 400mm Z axis (Bambu X1 can do 256mm; a Bambu P1S or Prusa XL can reach the required height in two sections joined by the existing junction rings).

Approach B is strongly preferred — it gives a single continuous visualization of the full vehicle wake and the two-ring fin interaction at all angles of attack.

At this scale and blockage (17.5%), the aerodynamics are visualization-only: confirmation of attached flow over the ogive, smoke tracing through the fin ring gaps, visualization of the booster/sustainer junction geometry, and qualitative confirmation that the aft fin ring produces attached spanwise flow at low AoA.

---

## 4. Test Programme Sequence

The four articles above map to a natural test progression, each building on the previous:

|Test|Article|Primary Objective|Method|Quantitative?|
|---|---|---|---|---|
|T-1|Nose cone|Boundary layer development, stagnation point|Smoke + laser sheet|Yes ($C_D$ extraction)|
|T-2|Single fin panel (half-span)|Fin lift curve slope, stall AoA, hinge separation|Smoke + AoA sweep|Yes (relative $C_L$)|
|T-3a|Ring 2 assembly + body stub|Body-fin junction, tip vortex|Smoke + laser|Visualization|
|T-3b|Ring 1 assembly + body stub|Body-fin junction, ring spacing interaction|Smoke + laser|Visualization|
|T-4|Full vehicle (approach A or B)|Complete wake topology, two-ring interaction|Smoke sweep|Visualization only|

### 4.1 Instrumentation Recommendations

For quantitative force data on T-1 and T-2, the force levels are small but manageable:

$$F_{drag,T-1} = q \cdot A_{nose} \cdot C_{D,nose} \approx 78.8 \times 4.28 \times 10^{-4} \times 0.04 \approx 1.3 \text{ mN}$$

$$F_{lift,T-2} = q \cdot S_{fin} \cdot C_L \approx 78.8 \times 5.44 \times 10^{-4} \times 0.5 \approx 21 \text{ mN}$$

A _TAL221 50g load cell_ driven by an _HX711 24-bit ADC_ and logged to any microcontroller (including an RP2040) is a perfectly appropriate and programmatically consistent choice. Resolution at 80 dB gain is approximately 0.4 mN — sufficient to resolve the drag on the nose cone and the lift on the fin panel. Mount the load cell in series with the sting, zero before each run, log at 10Hz, average over 10 seconds per point to suppress tunnel turbulence noise.

For smoke: the _Vosentech MicroFogger 5 Pro_ (cited in the source design) is adequate. Injection at the smoke-strut section upstream of the contraction produces clean streaklines by the time the flow reaches the test section.

For visualization enhancement: the _OxLasers 520nm laser line generator_ on the existing ceiling gantry produces a thin horizontal sheet that can be swept vertically to isolate specific spanwise stations. This is particularly useful for resolving the Ring 1/Ring 2 tip vortex interaction at the clocking plane.

---

## 5. Fabrication Specifications for WYVERN Test Articles

All articles are printed in _PETG-CF 20% CF_ to match the PTD structural material and to obtain a consistent surface finish across all models. ABS or standard PLA would introduce different surface roughness characteristics at the model scale, which at these Reynolds numbers noticeably affects boundary layer transition location.

|Article|Material|Layer Height|Walls|Infill|Est. Mass|Est. Print Time|
|---|---|---|---|---|---|---|
|Nose cone (1:3)|PETG-CF|0.15mm|2|0% hollow|~8g|~2.5h|
|Single fin panel + wall bracket|PETG-CF|0.15mm|4|40% gyroid|~12g|~3.5h|
|Ring 1 fin assembly + body stub|PETG-CF|0.15mm|3|20% gyroid|~25g|~7h|
|Ring 2 fin assembly + body stub|PETG-CF|0.15mm|3|20% gyroid|~18g|~5h|
|Full rocket body (two halves)|PETG-CF|0.20mm|2|10% gyroid|~45g|~12h|
|Sting adapter (Gridfinity base)|PETG|0.20mm|4|40%|~5g|~1h|
|AoA wall bracket (nose cone)|PETG|0.20mm|4|40%|~6g|~1.5h|

Total material: approximately 119g PETG-CF at approximately $3.81 in filament cost — negligible against the $632 vehicle build cost.

Use _0.15mm layer height_ on all aerodynamically-critical surfaces (nose cone, fin panels) to minimize surface roughness. At 1:3 scale, a 0.20mm layer is 0.60mm full-scale — a realistic surface flaw. Dropping to 0.15mm brings this to 0.45mm equivalent, which is still rough by full-scale aircraft standards but acceptable for educational visualization at this $Re$ regime.

Sand all external aerodynamic surfaces through 400 grit and apply two coats of _Rust-Oleum 2X primer_ spray. This reduces equivalent sand-grain roughness from approximately 50μm to approximately 5μm, keeping the surface in the hydraulically smooth regime for $Re < 10^5$.

---

## 6. Upgrade Recommendations Specific to the WYVERN Programme

The stock tunnel is adequate for nose cone and isolated fin work. Two targeted upgrades push it significantly further.

_Fan upgrade — AC Infinity Cloudline A8._ The upgrade doubles test section velocity from 5.4 to ~11.3 m/s and nearly doubles dynamic pressure. The upgrade diffuser STL (already in the archive) is designed for this fan and requires printing only two additional parts. Cost is approximately $80. For WYVERN testing this is essentially mandatory — at baseline velocity, the fin hinge forces are less than 2 mN and the load cell signal-to-noise ratio at 10Hz logging is borderline. At upgrade velocity the forces are 4× higher and the HX711 can reliably resolve them.

_Extended test section module._ A custom 400mm extended test section that replaces the stock 130mm frame. This is a parametric extension of `6-test-section-frame.stl` — add 270mm of prismatic cross-section with window slots on all four faces at 80mm × 400mm. Print in three junction-ring-coupled segments if build volume is limited. This enables T-4 as a proper single-article test rather than a split-article approximation. Design cost is approximately 4 hours of CAD time in any slicer-compatible modelling tool.

_Force balance integration._ The sting mount on the existing Gridfinity aero-strut base has a 6mm hex hole for roll indexing. A 4mm CF rod insert bonded into a PETG-CF adapter with a TAL221 load cell in-line and a waterproof JST-GH connector (already the programme's standard connector) passing through the test section floor makes the instrumentation fully hot-swappable and consistent with the existing avionics wiring standard.

---

## 7. Summary of Limitations and What the Data Is Worth

The WYVERN tunnel programme will not produce flight-representative aerodynamic coefficients. The two-decade Reynolds number gap means the tunnel drag numbers should not be used to calibrate OpenRocket models or validate the Barrowman $C_N$ calculations. What the tunnel _will_ produce, at low cost and before first flight, is genuinely useful:

Confirmation that the _Von Karman ogive produces attached flow_ without separation over the full AoA range tested — if separation is visible at 10° in the tunnel, it will certainly occur in flight at the same AoA regardless of Reynolds number.

Confirmation that the _fin panels are free of leading-edge separation bubbles at small deflection angles_ — the double-wedge 4% t/c profile at $AR \approx 1.0$ is known to be separation-resistant but the junction region with the body is less predictable.

Visualization of the _Ring 1/Ring 2 clocking interaction wake_ — the 45° offset between rings creates an interdigitated fin tip vortex field in the wake that OpenRocket does not model and that no hand calculation captures. This is exactly the kind of insight a flow visualization tunnel provides that analysis cannot.

Evidence that the _aft fin root/gimbal bay junction is not creating separated flow_ that would degrade control effectiveness — the 15mm annulus with protruding servo linkage hardware is geometrically messy and worth checking in smoke.

Any anomalous result from the tunnel is a prompt to revisit the design or adjust the OpenRocket model, not a direct coefficient replacement.

The tunnel is designed ground-up around the WYVERN test programme constraints rather than adapted from the STEM reference design. The key decisions and their justification:

_Test section 150 × 150 mm square._ The STEM tunnel's 80 × 130 mm section put the full 1:3 rocket at 17.5% blockage — uncorrectable. The new section brings the full rocket at 0° AoA to 7.9%, which is Maskell-correctable, and isolated fin assemblies below 7%. The square cross-section also means roll sweeps are geometrically consistent at all roll angles, which matters for the 45° Ring 1/Ring 2 clocking tests.

_9:1 contraction ratio._ The STEM tunnel uses 4:1, which gives a turbulence intensity of roughly 0.5–1.0% in the test section. Upgrading to 9:1 with two-screen conditioning brings estimated TI to 0.21%, which is the difference between seeing laminar separation bubbles in smoke (requires TI < 0.3%) and watching them smear into turbulent noise. The downside is a 900 mm contraction cone — the dominant length driver on the 2.47 m OAL.

_Bell 5th-order polynomial contraction profile._ The zero-slope, zero-curvature boundary conditions at both ends guarantee no adverse pressure gradient at either junction. A simpler linear or cubic taper would produce inflection-point separation on the contraction walls at high contraction ratios — particularly dangerous at 9:1.

_4° diffuser half-angle._ Barlow, Rae and Pope (1999) place the separation threshold at ~4–5° for a turbulent boundary layer. At 4.0° exactly the diffuser recovers static pressure without separation. The square-to-circle transition is handled by linearly growing the corner radius from 0 to 100 mm over the 220 mm diffuser length, maintaining mass conservation at each station.

_Contraction print strategy._ The 450 × 450 mm settling chamber exterior is 456 × 456 mm — impossible as a single print on any home machine. The solution is six 150 mm-long tunnel sections each with a 156 × 156 mm exterior cross-section, all of which fit on a 180 mm bed. The taper from 450 to 150 mm internal is distributed across these sections per the Bell polynomial table. The Bambu X1 or Prusa XL is only required for the diffuser.

The $433 total is well within the PDR-002 programme budget context and represents roughly one replacement set of motors.

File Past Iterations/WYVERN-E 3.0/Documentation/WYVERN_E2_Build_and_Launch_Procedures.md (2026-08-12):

# WYVERN-E 2.0 — Build & Launch Procedures

### A Skylight Rocketry Venture
##### 84 mm 2-Stage Magnetic-TVC 3D-Printed Research Vehicle

> *Safety first.* This vehicle carries energetics (motors, black-powder ejection charges,
> igniters). Handle per NAR/Tripoli safety codes. Two-stage + onboard energetics operations
> require RSO approval. Never connect igniters/charges until the vehicle is on the pad and the
> range is clear. Eye protection during ground tests and ejection charge work.

## Part A — 3D Printing

### A.1 Print settings (by material)

| Part group | Material | Walls | Infill | Notes |
|---|---|---|---|---|
| Body tubes, booster, couplers | PETG-CF | 4 perim (2.0 mm) | 35% gyroid | 0.2 mm layer; dry filament; 250–260 °C |
| Nose cone, camera pod | ASA | 4 perim | 20% | Enclosure printer; 240–250 °C; brim |
| Fins | PC-FR | solid (4 mm) | 100% | 270–290 °C; anneal optional |
| TVC gimbal/cradle, test stand | PC-FR | 4 perim | 40% | 270–290 °C; flame-rated zone |
| Wind tunnel mount + fan collar | PLA | 3 perim | 20% | 200–210 °C |

### A.2 Print order & files (`3DP/Rocket/`, `3DP/WindTunnel/`, `3DP/TestStand/`)

1. `01_nose_cone` (ASA) — print tip-up, supports off; light support in shoulder.
2. `02_recovery_bay`, `03_avionics_bay`, `05_stage2_tvc_bay`, `09_stage1_booster_body`
   (PETG-CF) — print vertically; the booster has the fin can + motor mount integrated.
3. `07_interstage_coupler` (PC-FR).
4. `08_fin_single` (PC-FR) — print 4× for flight; print extra candidate geometries for the tunnel.
5. `06_tvc_gimbal_mech` (PC-FR) — supports under trunnions.
6. `04_pcb_internal_mount` (PETG-CF), `10_camera_pod_fairing` (ASA).
7. GSE: `WindTunnel/WT_fin_test_mount`, `WindTunnel/WT_120mm_fan_collar` (PLA);
   `TestStand/TS_base_plate`, `TS_motor_tower`, `TS_loadcell_bracket` (PC-FR).
8. `00_full_assembly` / `11_outer_shell_full` are reference/visual STLs (not printed for flight).

Each part is provided as `.stl` (print) and `.step` (CAD edit). Regenerate or re-parametrize
with `3DP/_generator/gen_rocket.py`.

### A.3 Post-processing

- Ream coupler bores to a snug slip fit (test fit before any bonding).
- Tap/clean threaded coupler interfaces.
- Bond fins into the booster fin-can slots with 2-part epoxy; fillet the root.
- Install the motor retainer ring; verify 29 mm motor slides into the mount tube.

## Part B — Avionics (FCM)

### B.1 PCB fabrication

1. Open `PCB/FCM_KiCAD/WYVERN_E2_FCM.kicad_pcb` in KiCad 7/8/9.
2. **Promote to 4-layer** (Board Setup → Physical Stackup) per PCB doc §6; move 12 V / V_SOL /
   5 V / 3.3 V polygons to the inner power layer.
3. Finish the 4 open nets interactively (press `X`, follow ratsnest): RF_ANT as a 50 Ω jog to
   the edge SMA, and the +5V_USB / boot-cap stubs. The JLCPCB fab package is in
   `PCB/FCM_KiCAD/gerbers/` (upload `WYVERN_E2_FCM_gerbers.zip`; add BOM + CPL for assembly).
4. Run DRC; re-export Gerbers (or use the provided `gerbers/` package); fabricate ENIG, 2 oz inner copper.

### B.2 Assembly & bring-up

1. Reflow/hand-solder per the BOM; inspect the RP2350B QFN-80 and fine-pitch sensors.
2. Power over USB-C first (no battery); confirm 3.3 V and 5 V rails.
3. Flash firmware; verify each sensor on its bus (ICM SPI, BME/LIS/INA/BNO I2C), NAND +
   microSD read/write, camera capture.
4. **Solenoid loop test** (bench, no motor): command each coil; confirm 20 kHz PWM, shunt
   current readback, and gimbal motion to ±5°; verify spring return on power-off.
5. Mount the FCM to `04_pcb_internal_mount`; slide into the avionics bay rails; route the
   camera to the pod window and the BNO055/coil harnesses.

## Part C — Ground Testing

### C.1 Motor static fire (test stand)

1. Stake `TS_base_plate` into firm dirt; assemble tower + load-cell bracket; install the
   Wishiot bar cell (10 kg) with HX711 → Metro M4 + microSD.
2. **Calibrate** with an Estes E16-4 (known 32.5 N·s); compute N/count; integrate to confirm
   impulse.
3. Static-fire a G78 and an F25; log thrust curves. **Watch for cell clipping at the G78 peak
   (101.9 N > 98 N)** — if clipped, fit a 20 kg cell and re-calibrate.
4. Compare measured $I_t$ / $\bar F$ to published; update the trajectory model.

### C.2 Wind-tunnel fin down-select

1. Print candidate fins (one geometry per print). Assemble the Printables modular tunnel +
   120 mm fan adapter; fit `WT_120mm_fan_collar` and `WT_fin_test_mount`.
2. Mount ONE fin in the turntable; sweep angle of attack via the 15° index holes.
3. Measure normal force / pressure at matched Reynolds number; repeat per candidate.
4. Select the geometry with the best lift-to-drag and CP behavior; this becomes the flight fin.

### C.3 Ground ejection test

1. With the recovery bay packed (chute + 6 ft Kevlar), test-fire the FFFFg charge in the
   E-Match Mate canister; confirm clean separation and full chute extraction.
2. Tune charge mass; repeat for both the booster and main events.

## Part D — Pre-Flight Assembly (at the field)

1. Pack the main chute (18″, or 24″ if selected) with the 6 ft Kevlar shock cord; nose
   shoulder dry-fit.
2. Pack the booster chute; set the interstage coupler with the 2nd-stage igniter channel clear.
3. Install motors: F25 in the sustainer gimbal cradle; G78 in the booster; retainers on.
4. Charge/secure the 12 V NiCd pack; connect to the FCM (XT60). Confirm boot, GPS/baro zero,
   storage armed.
5. **Energetics last, on the pad**: install the First Fire Jr. sustainer igniter; connect the
   MJG initiators + ejection canisters to the onboard FCM pyro channels. Verify continuity reads
   on the FCM (drogue/main/ignition).
6. Set the onboard FCM deploy thresholds (baro apogee → main; drogue per booster recovery plan).

## Part E — Launch (Estes Pro Series II rail + controller)

1. Place the vehicle on the rail; verify free travel. **Use the rail extension** (rail-exit
   velocity is marginal at 10.0 m/s — Math §4).
2. Arm in this order: recovery (FCM pyro) → TVC enable → FCM "armed." Confirm the staging
   interlock is active (drogue inhibited until sustainer ignition + separation).
3. Clear the range; RSO go.
4. Launch. Flight sequence: G78 boost → booster burnout → sustainer ignition (TVC active) →
   booster separation + booster chute → sustainer coast → apogee → main chute.
5. Track the rocket visually through descent; recover and note landing coordinates (all flight data is on the onboard SD-NAND/microSD).

## Part F — Recovery & Post-Flight

1. Recover both stages. Safe any unfired energetics before handling.
2. Power down the FCM; pull the microSD and/or download NAND over USB-C.
3. Extract flight video; review TVC loop logs, attitude, and the full sensor record.
4. Inspect the airframe, gimbal, and fins; log any damage and descent-rate adequacy.
5. Update the trajectory and TVC models with measured data; iterate.

## Appendix — Field Checklist (quick)

- [ ] Chutes packed (main + booster), shock cords attached
- [ ] Motors installed + retained (F25 sustainer, G78 booster)
- [ ] Battery charged + connected; FCM booted, storage armed
- [ ] Igniter + ejection charges connected (on pad); continuity verified
- [ ] Onboard FCM deploy thresholds set
- [ ] Rail extension fitted; vehicle travels freely
- [ ] Staging interlock confirmed; TVC enabled
- [ ] Range clear; RSO go

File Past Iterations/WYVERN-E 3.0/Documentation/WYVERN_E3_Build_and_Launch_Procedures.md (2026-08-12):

# WYVERN-E 3.0 — Build & Launch Procedures

### Skylight Rocketry · off-the-shelf Pi-5 two-stage TVC vehicle
## 1. Print plan (all PC-FR except nose)

| Part | Material | Notes |
|---|---|---|
| Nose cone | ASA | mass-sensitive, cool |
| Recovery bay, FC bay, TVC bay, **bulkhead**, booster body, interstage | PC-FR | 100 % flame/heat zones; ~35 % infill, 1.6 mm walls |
| Fins (oversized) | PC-FR | solid (4 mm), 100 % infill |
| Fin test articles (RQ1/RQ2) | PLA Basic | one geometry at a time for the tunnel |

Freeze a single Bambu X1C profile (0.4 mm nozzle) and reference it for all flight parts.

## 2. Flight-computer assembly (off-the-shelf)

1. Mount the **Raspberry Pi 5 + active cooler** to the FC-bay sled; seat the **Camera Module 3**
   ribbon to the side window.
2. Wire the I²C bus through a **TCA9548A mux** (the three BNO085 share an address): channel 0 =
   gimbal BNO085, ch 1 = central BNO085, ch 2 = nose BNO085; LSM6DSO32, LIS2MDL, BMP280, BME688
   on the remaining channels / direct bus.
3. Mount the two **microSD breakouts** (SPI): one for H.264 video, one for the sensor log.
4. Wire the **power system**: 3S pack → USB-C PD/BMS board; 5 V/5 A buck → Pi 5 GPIO 5 V rail;
   6 V buck → servo rail (System B); 11.1 V direct → solenoid bus (System A). Inline fuse + switch.
5. Install the **RRC3+** (recovery + 2nd-stage ignition) with hardware continuity on each channel.
6. Wire the **remove-before-flight jumper** in the arm path (see §5). Verify on bench: all sensors
   enumerate, both microSD read/write, camera captures.

## 3. TVC assembly (build the test article)

- **System A (solenoid):** mount 3× 12 V pull-solenoids at 120° on the gimbal ring; wire to the
  3-channel MOSFET driver; fit return springs; route coil leads through the bulkhead slots.
- **System B (servo):** mount 3× ~35 kg·cm servos; install ball-link linkages to the gimbal;
  wire to the PCA9685; route servo leads through the bulkhead slots.
- The **bulkhead** seals the FC bay from the TVC/motor bay; only the actuator leads + the gimbal
  BNO085 lead pass through its slots. Verify the gimbal swings ±5° freely and returns to neutral.

## 4. Recovery

24″ main + 1/8″ tubular Kevlar shock cord (8 ft) on the nose↔FC-bay bulkhead. Black-powder
ejection in the E-Match Mate canister, MJG initiators on the RRC3+ drogue/main channels.

## 5. Pad / arming sequence

1. Install motors: **F booster** (RMS-29/40) in the booster mount, **G25W-10A** (RMS-29/120) in
   the gimbaled sustainer mount. Igniter on the sustainer per RRC3+ 2nd-stage channel.
2. With the **RBF jumper INSERTED**, the FC is in standby and all pyro/ignition outputs are held
   safe. Power on; confirm sensors logging, microSD armed, camera recording.
3. On the rod, **pull the RBF jumper** → FC armed. Confirm the launch-detect threshold is primed
   (LSM6DSO32 / BNO085).
4. Clear the pad; fire the booster from the launch controller.

## 6. Flight sequence

1. Liftoff on the F booster; accelerometer threshold (> 3 g sustained) starts the flight state
   machine. Fins stabilize the booster phase.
2. Booster burnout + drag separation; RRC3+ arm-gate confirms staging state.
3. RRC3+ fires the **G25W**; **TVC active from ignition** — stabilize, then command the maneuver
   across the 4.7 s burn.
4. Apogee → RRC3+ drogue, then main. Recover.

## 7. Post-flight

Pull both microSD cards; copy the video + sensor log. Cross-check the gimbal BNO085 (actual
thrust-vector attitude) against the FC/nose BNO085 and the commanded gimbal angles. Inspect the
gimbal, motor mounts, and bulkhead pass-throughs. Swap the TVC system for the next A/B block.

## 8. Pre-launch checklist

- [ ] All parts printed in the frozen PC-FR profile; gimbal swings ±5° and returns to neutral
- [ ] Pi 5 boots; 3× BNO085 + LSM6DSO32 + LIS2MDL + BMP280 + BME688 enumerate; both µSD R/W OK
- [ ] Camera records to its µSD; flight log writes to the other
- [ ] Battery charged (USB-C); 5 V / 6 V / 11.1 V rails verified under load
- [ ] RRC3+ continuity good on drogue, main, and 2nd-stage channels
- [ ] Motors installed (F booster RMS-29/40, G25W-10A RMS-29/120); sustainer igniter in
- [ ] RBF jumper inserted (FC safe); pulled only on the rod
- [ ] Recovery packed; shock cord + chute checked; RSO brief complete

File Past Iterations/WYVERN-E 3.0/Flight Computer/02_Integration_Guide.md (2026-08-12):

# WYVERN-E 3.0 — Flight Computer Integration Guide

### Wiring, assembly, and first power-on bring-up

## 1. Before you start

Flash Raspberry Pi OS (64-bit, Bookworm) to a boot microSD (separate from the two SPI flight
cards). Enable I²C, SPI, UART, and the camera in `raspi-config`. Install deps:

    python3 -m venv ~/wyvern && source ~/wyvern/bin/activate
    pip install -r test_code/requirements.txt

## 2. I²C sensor harness (STEMMA QT)

1. Wire I²C1 (GPIO2 SDA, GPIO3 SCL, 3V3, GND) to the *TCA9548A* with a male JST-SH cable.
2. Daisy each sensor to its mux channel with the female JST-SH cables (qty 3 of each in the cart):
   ch0/1/2 = the three *BNO085* (gimbal, FC, nose); ch3 *LSM6DSO32*; ch4 *LIS2MDL*; ch5 *BMP280*;
   ch6 *BME688*. The gimbal BNO085 lead routes through the bulkhead slot into the TVC bay.
3. Run `python3 test_code/i2c_scan.py` — every channel must report its expected address.

## 3. Storage and camera

1. Mount the two SPI microSD breakouts: #1 CS→CE0/GPIO8 (`/mnt/sd_video`), #2 CS→CE1/GPIO7
   (`/mnt/sd_log`); share MOSI/MISO/SCLK. Add both to `/etc/fstab`.
2. Seat the Camera Module 3 ribbon to the CSI-2 port; route to the FC-bay side window.
3. Verify: `python3 test_code/microsd_test.py` and `python3 test_code/camera_test.py`.

## 4. Power

1. 3S Li-ion pack → IP2368 USB-C PD/BMS board. Master switch + inline fuse on the pack +.
2. 5 V/5 A buck → Pi 5 5 V rail (GPIO pins 2/4 + GND). 6 V UBEC → servo rail (System B only).
   11.1 V bus direct → solenoid bus (System A) and RRC3+.
3. Confirm 5.0 V, 6.0 V, and 11.1 V under load *before* connecting the Pi 5.

## 5. Recovery / ignition controller

1. Install the *RRC3+*: VBAT + GND from the 11.1 V bus; UART to GPIO14/15.
2. Wire DROGUE (apogee), MAIN (150 m), AUX (G25W 2nd-stage igniter). Hardware continuity check
   on each channel with the igniters disconnected.
3. Mount the *Jolly Logic Altimeter 2* on its own battery as an independent backup log.

## 6. TVC backend (build the A/B article under test)

System A — solenoid: mount 3× 50 N solenoids at 120° on the gimbal ring; IRF520 gates to
GPIO12/13/18; 1N4007 flyback across each coil; N52 magnets set the return/detent; coil leads
through the bulkhead slots. Grease pivots with Super Lube; bond brackets with J-B Weld.

System B — servo: mount 3× DS3235 servos; ball-link to the gimbal; signal to PCA9685 CH0/1/2;
V+ from the 6 V UBEC. Set `set_pulse_width_range(500,2500)` and neutral = 90°.

Verify the chosen backend: `tvc_solenoid_test.py` or `tvc_servo_test.py`. Gimbal must swing ±5°
and return to neutral.

## 7. Arm path

Wire the remove-before-flight jumper into GPIO17 so *inserted = safe*. With it inserted, confirm
in software that RRC3+ AUX/DROGUE/MAIN are masked. The jumper is pulled only on the rail.

## 8. First full bring-up

Run `python3 test_code/preflight_selftest.py`. It exercises every subsystem and prints a PASS/FAIL
table; do not proceed to a flight build until it is all-PASS. Then dry-run the control law with
`python3 test_code/tvc_control_loop.py` (no hardware) to confirm the loop tracks the maneuver and
clamps at ±5°.

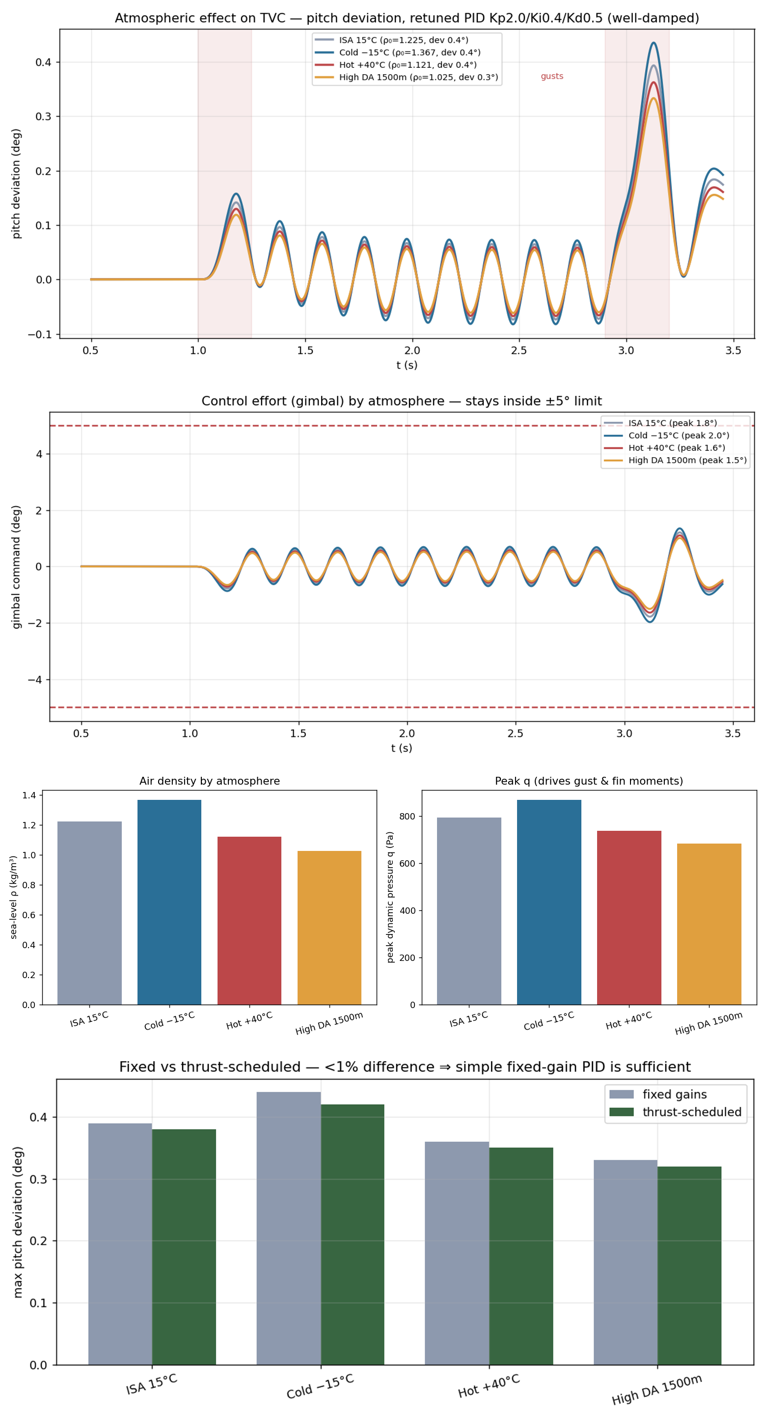
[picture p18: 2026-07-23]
Simulations/plots_atmos/_atmos_montage.png

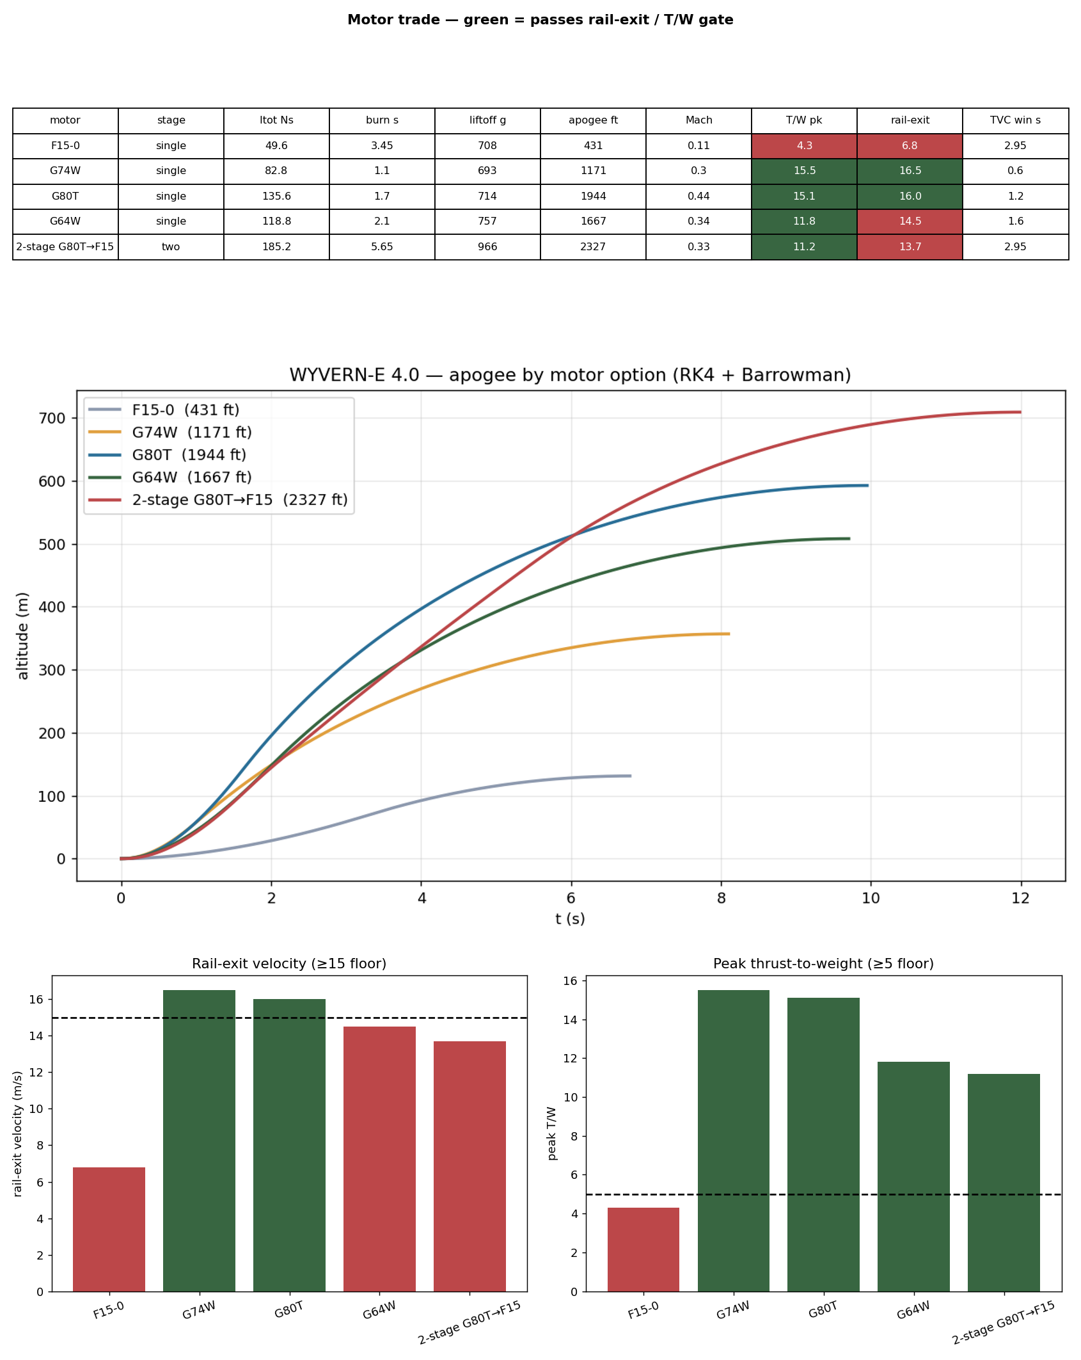
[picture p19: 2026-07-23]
Simulations/plots_motor/_trade_montage.png

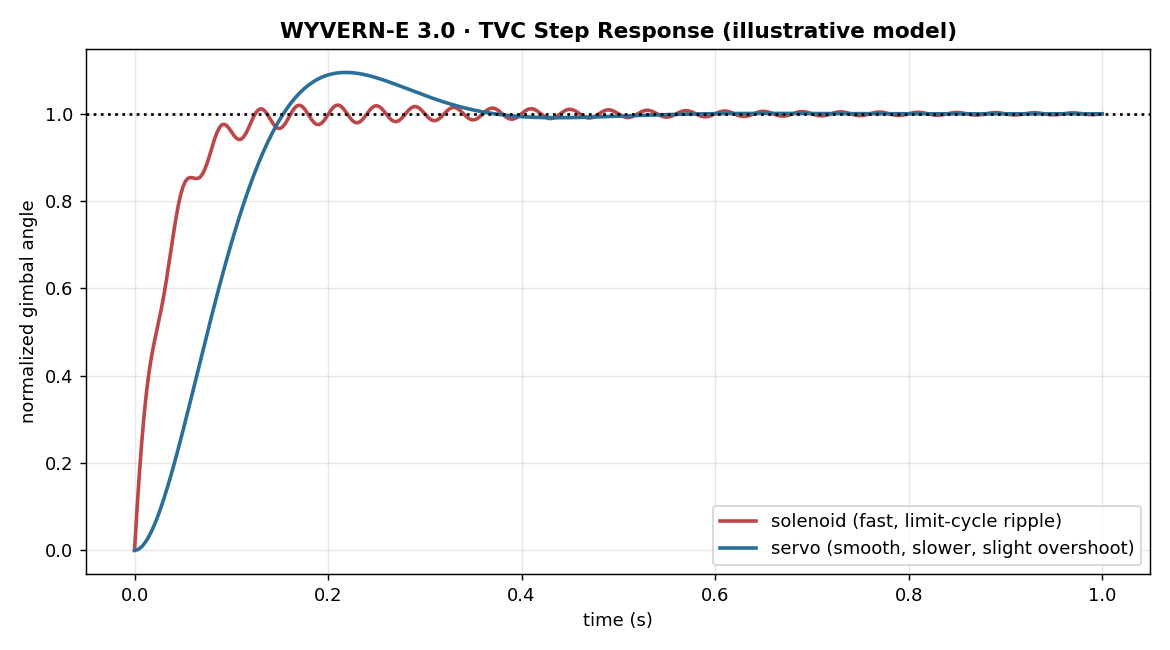
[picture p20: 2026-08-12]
Past Iterations/WYVERN-E 3.0/Simulations/plots3/08_tvc_step_response.png

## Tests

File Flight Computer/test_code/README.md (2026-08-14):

# GTR70E WYVERN, Test Programs

**Raspberry Pi Pico 2 W perfboard** Arduino sketches + host monitor. Build with the
**Arduino-Pico core** (earlephilhower), board **"Raspberry Pi Pico 2 W"** (`rpipico2w`). NOT any
Pico/Pico 2 W module profile. Flash each, watch USB serial at 115200.

| File | Tests |
|---|---|
| `t1_i2c_scan.ino` | single shared I²C bus (GP0/GP1, no mux), every sensor enumerates, including bench-confirming INA226's real address |
| `t2_imu_grv_deflection.ino` | bay BNO085 0x4B vs. gimbal BNO085 0x4A (**Game Rotation Vector**) attitude agreement, and gimbal-relative deflection |
| `t3_servo_sweep.ino` | RP2350 hardware-PWM ±8° gimbal sweep (GP2/GP3) |
| `t4_sensors_sdlog.ino` | BME688 (no BMP388 populated on this board rev) → SPI microSD CSV @100 Hz |
| `host_monitor.py` | reads the flight computer's USB serial, tabulates preflight PASS/FAIL |
| `selftest.py` | preflight checklist |

**Libraries (Library Manager):** Adafruit_BNO08x, Adafruit_BNO085, Adafruit_BME680, plus the
Arduino-Pico built-ins `Servo`, `Wire`, `SPI`, `SD`.
**Pins:** I²C0 (single shared bus) GP0/GP1, SPI0 microSD MISO/CS/SCK/MOSI = GP8/GP9/GP10/GP11,
servos GP2/GP3, see `../01_FlightComputer_Spec.md` §3.

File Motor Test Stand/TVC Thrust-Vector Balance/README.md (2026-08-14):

# Servo TVC Test Stand, 3-Axis Load Balance

Printable **PETG-CF** parts for the servo-gimbal thrust-vector balance (RQ1/RQ5, see
`WYVERN_E4_GSE_TestStands.md` §2). Resolves the full commanded thrust vector via one axial (Z)
and two lateral (X, Y) strain-gauge load cells through flexures.

- `TVC_balance_base.*`, fixed base with the 3 load-cell pedestals + 4 corner mounting bosses.
- `TVC_balance_thrust_block.*`, motor + gimbal mount, doubles as the gimbal's pitch-axis trunnion
  mount for this bench rig (through-holes matching the gimbal's 3.2mm pivot bore, see
  `3D parts/_generator/gen_rocket4.py` `gimbal()`/`tvc_balance()`).
- `TVC_balance_flexure_template.*`, spring-steel flexure cutting/bending guide (not a functional
  plastic part).
- `TVC_balance_hx711_mount.*`, HX711 breakout mounting plate.

Instrumentation: **5 kg axial + 2x 1 kg lateral** strain-gauge load cells, 3x HX711, read by one
of the three custom RP2350 flight-computer PCBs at 80 SPS (`WYVERN_E4_GSE_TestStands.md` §2).
The magnetic-solenoid TVC stand (`WYVERN Project/3D parts/MTVC/`) is a physically separate rig,
not generated by this script.

Generated by `../../3D parts/_generator/gen_rocket4.py`. Fastener standard: M3 heat-set brass
inserts (4.2mm pilot, 8mm boss OD). Load-cell and HX711 hole spacing are TYPICAL-CLASS figures
for the specific Adafruit parts in the BOM, verify with calipers against the actual hardware
before the final print (see the generator's module docstring and `CONFLICTS.md` #9).

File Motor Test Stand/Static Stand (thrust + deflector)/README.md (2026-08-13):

# Motor Test Stand, Ground Support Equipment

Printable **PETG-CF** parts for the vertical load-cell thrust stand that produces the **RQ1
static thrust-curve baseline** (Estes F15-0 and E16-4). PETG-CF here is a GSE choice, not a
vehicle-material choice, the fixture sits beside a 3.45 s plume, so it does not follow the
vehicle's ASA-Aero/PETG-CF/PC-FR zoning. Jetvane coupon testing runs on this same stand (see
`WYVERN_E4_GSE_TestStands.md` §1) as a blast-shield materials screen, not a vane-deflection test;
this stand's own printed geometry below is axial-thrust-only regardless.

- `TS_base_plate.*`, ground plate, bolts the motor tower and load-cell bracket down and provides
  4 corner mounting bosses.
- `TS_motor_tower.*`, vertical motor cradle (29mm-class F15 case, slip fit) + load-cell seat.
- `TS_loadcell_bracket.*`, bar load-cell mounting bracket (fixed end + sensing-end interface).

**Instrumentation:** **1x 5 kg axial load cell + HX711**, read by a Raspberry Pi Pico / Pico 2 W
DAQ at 80 SPS, matching `WYVERN_E4_GSE_TestStands.md` §1. Calibrated with known hanging masses to
~2.5 kg, then commissioned against a published E16-4 curve.

Generated by `../../3D parts/_generator/gen_rocket4.py`. Fastener standard: M3 heat-set brass
inserts (4.2mm pilot, 8mm boss OD) at every bolted joint; load-cell hole spacing is a
TYPICAL-CLASS figure for the Adafruit 5kg strain-gauge cell, verify with calipers against the
actual part before the final print (see the generator's module docstring).

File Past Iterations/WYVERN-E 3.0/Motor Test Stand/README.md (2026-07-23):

# Motor Test Stand — Ground Support Equipment

Printable PC-FR parts for the vertical load-cell thrust stand used to characterize 29 mm motors and to run the E16-4 jetvane material-erosion test (RQ3).

- `TS_base_plate.*` — staked ground plate.
- `TS_motor_tower.*` — vertical motor cradle + load-cell seat.
- `TS_loadcell_bracket.*` — bar load-cell mounting bracket.

Instrumentation: Wishiot 10 kg bar load cell + HX711, read by an Adafruit Metro M4 logging to microSD, calibrated with an Estes E16-4. Generated by `../3D parts/_generator/gen_rocket.py`.

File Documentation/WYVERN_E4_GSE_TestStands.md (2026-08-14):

# GTR70E WYVERN, Ground Test Stands & Motor Plan

**Authors:** Swaroop Sahoo, Chris Liu, Allison Hong  
**Program:** GTR70E WYVERN

Four instrumented ground-test rigs, one per research question that needs physical validation before
flight: static fire (RQ2 materials + calibration), servo TVC stand (RQ1/RQ5), magnetic TVC stand
(RQ1/RQ5), wind tunnel (RQ3/RQ4). Jetvane testing runs on the static-fire stand as a materials
screen. A fifth fixture, the RQ2 bend-to-fracture bench rig in section 5, is uninstrumented dead
weight and needs neither a motor nor a load cell.

## 1. Static fire test stand, calibration, thrust curves, jetvane materials screen
Axial-only load path (1x 5 kg cell + HX711) with a **steel blast deflector**, sized for the F15-0's
3.45 s burn thermal case. Three jobs run on this one stand:

- **RQ1 baseline**: total impulse, average and peak thrust, burn time and curve shape for the
  F15-0, the reference curve both TVC stands are compared against.
- **Stand/DAQ calibration**: known hanging masses calibrate the load cell before every firing
  campaign; E16-4 commissioning firings validate the calibrated chain against a published curve.
- **RQ2 jetvane blast-shield screen**: this is a materials screen, not a
  vane-deflection test. A flat coupon plate of each candidate material, 5 mm thick and printed at
  100% infill, is mounted directly in the exhaust path like a blast shield and fired on. The motor
  runs straight into the plate; the response is melt-through, surface ablation depth, and slag
  buildup, not thrust or deflection. Five materials go through the screen: PLA, PETG-CF,
  ASA-Aero, PC, and PC-FR. ABS was dropped from the program 2026-08-14. Any material that survives
  5 mm without melting through gets retested at 4 mm, then 3 mm, then 2 mm, until it fails, giving
  a failure-thickness ranking across the five candidates rather than a single pass/fail. The BME688 already on the stand logs plume-adjacent
  temperature alongside each firing so the melt/slag result has a temperature record to go with it.

## 2. Servo TVC test stand
The servo-gimbal actuator bolts to a thrust block restrained from a fixed base by **three
strain-gauge load cells through flexures**: one **axial (Z)** and two **lateral (X, Y)**. Resolves
the full thrust vector, magnitude *and* direction:

$$T=\sqrt{F_x^2+F_y^2+F_z^2},\quad \theta=\arctan\frac{\sqrt{F_x^2+F_y^2}}{F_z},\quad
\phi=\operatorname{atan2}(F_y,F_x)$$

Sized for the small motors here: **F15 peak 25.3 N**, side force at ±8° ≈ **3.5 N** → a **5 kg
axial + two 1 kg lateral** cells + 3× HX711 → a Raspberry Pi Pico / Pico 2 W DAQ at 80 SPS. Logging
commanded vs measured (θ, φ) gives bandwidth, slew, overshoot, and steady-state error for the servo
system, this is the rig the flight vehicle's actual TVC gets qualified on (`wyvern4_gse_servo_rig`).

One HX711 per axis is not optional. The part multiplexes its two channels through a single ADC and
needs settling time after a channel switch, so sharing one chip across two axes forfeits
simultaneous sampling and smears the vector reconstruction. Program total is four: three here, one
on the static stand. Strap RATE high for 80 SPS rather than the 10 SPS default; at 80 SPS the 3.45 s
F15 burn yields roughly 275 samples, of which only about 16 land on the ignition transient, so treat
the reported peak as a lower bound and the total impulse as the trustworthy figure.

No bend-rig cell is carried. The program's cell count is four: two 1 kg lateral, two 5 kg axial.
RQ2's structural half runs as a dead-weight bend-to-fracture test with no load cell at all, spec'd
in section 5.

## 3. Magnetic TVC test stand
A second, physically separate rig (`gtr70e_wyvern_gse_solenoid_rig`) using the same three-load-cell
flexure and DAQ chain as the servo stand, but with the magnetic-solenoid gimbal actuator in place
of the servo gimbal. Running the identical instrumentation chain on both stands is what makes the
**RQ1 magnetic-vs-servo A/B comparison** valid, commanded vs measured (θ, φ) from each stand feed
directly into the same bandwidth/slew/overshoot/steady-state-error metrics for a like-for-like
comparison. Only the servo system flies (RQ1 answers which actuation type wins on the bench; the
flight vehicle carries the winner's specs into the record either way).

## 4. Wind tunnel, aerofoil performance testing (RQ3/RQ4)
Bench aerofoil rig (`Wind Tunnel/`) for direct measurement of fin aerofoil performance, 
lift/drag/stall behavior across the flown fin's angle-of-attack range, to calibrate against the
Barrowman-derived stability numbers in `WYVERN_E4_Stability_FinSizing.md`. This is the RQ4
wind-tunnel-vs-flight comparison: tunnel-measured coefficients here, flight-derived weathercocking
and stability margin from telemetry (`Simulations/plots_val/05_wind_weathercock.png`) after launch.
Feeds RQ3 (fin aerofoil selection) directly, whichever aerofoil the tunnel run favors is the one
committed to the flown fin can.

## 5. RQ2 bench bend-to-fracture fixture

Not a motor stand and not instrumented. A printed coupon is simply supported on two rollers, a
string and hanger yoke hangs from mid-span, and dead weight is added in steps until the coupon
snaps. The force reference is gravity, which is a better standard than a load cell that would
itself have been calibrated with known masses. Reported result is the mass at fracture, converted
to flexural strength.

| Parameter | Value |
|---|---|
| Coupon | 2.0 mm thick × 15 mm wide × 100 mm long, printed flat, identical parameters across materials |
| Support | two 6 mm rollers, 80 mm span, simply supported |
| Load | string + hanger yoke at mid-span, dead weight in steps |
| Design ceiling | 6 kg (59 N) |
| Samples | 5 coupons per material, 5 materials, 25 total |

Flexural strength at fracture follows from the simply-supported mid-span load case:

$$\sigma_f=\frac{3FL}{2bd^2}=\frac{3(0.080)}{2(0.015)(0.002)^2}F$$

which reduces to a clean conversion for this exact geometry: 2.0 MPa per newton, or

$$\sigma_f\;[\text{MPa}]=19.6\,m\;[\text{kg}]$$

Every kilogram hanging on the yoke is 19.6 MPa of flexural stress in the coupon. The 6 kg ceiling
corresponds to 118 MPa, above every candidate's published flexural strength, so the fixture cannot
be the limiting element.

Predicted fracture masses, from published FDM flexural strengths for each class:

| Material | Flexural strength (printed, typ.) | Predicted fracture mass |
|---|---|---|
| PC | 85–100 MPa | 4.3–5.1 kg |
| PC-FR | 80–95 MPa | 4.1–4.8 kg |
| PLA | 70–90 MPa | 3.6–4.6 kg |
| PETG-CF | 60–80 MPa | 3.1–4.1 kg |
| ASA-Aero (foamed) | 20–35 MPa | 1.0–1.8 kg |

Printed flat with the layers perpendicular to the load, interlayer adhesion rather than bulk
strength governs, so expect real fractures 20–40 % below these numbers. Working range is roughly
0.9 to 4 kg. Load in 500 g steps to bracket the failure, then bisect in 100 g steps on the
remaining coupons of that material.

Mid-span deflection at fracture runs 9 to 22 mm depending on modulus, so leave 40 mm of clearance
under the coupon and expect the weight to drop that far the instant it snaps. Land it on foam or
sand from under 100 mm, wear eye protection, and keep hands and feet out from under the yoke —
PC-FR and PETG-CF fail brittle and throw fragments.

## 6. Motor plan & counts (verified specs, jetvane blast-shield screen included)
| Motor | Spec (verified) | Use |
|---|---|---|
| **Estes F15-4** | 49.6 N.s, 14.4 N avg / 25.3 N pk, 3.45 s, 4 s delay + ejection | **flight only** (ejection charge = recovery) |
| **Estes F15-0** | 49.6 N.s, 14.4 N avg / 25.3 N pk, 3.45 s, 0-delay (plugged) | **ground stands** (no ejection into fixtures) |
| **Estes/AeroTech E16-4** | ~16 N avg, E-class | stand commissioning firings |

**Counts:**
- *F15-4* = **4 (flight only)**: the ejection charge is the recovery system.
- *F15-0 (plugged)* = **13-20** for ground, split three ways: 6 TVC-stand firings (3 servo + 3
  magnetic), 2 static thrust-curve firings, and the jetvane blast-shield screen, which is adaptive
  rather than a fixed count. Five materials at up to 4 thickness steps each (5/4/3/2 mm, stopping at
  first melt-through) tops out at 20 firings if every material survives to 2 mm; in practice most
  candidates are expected to fail by 4 mm, so budget for roughly 10-14 firings and treat 20 as the
  worst-case ceiling. Plan for **13 firings as the low estimate plus a spares allowance for repeats**.
  Ground fixtures use the 0-delay F15-0 so no ejection charge fires into the stand; the thrust curve
  is identical to the F15-4 (same F15 propellant), so ground data transfers directly to the flight motor.
- *E16-4 (calibration)* = **6 recommended** (3 per TVC stand for repeatability); **4 is the floor**
  (2/stand). Load cells are *calibrated* with known hanging masses, free and precise; the E16 firings
  *commission and validate* the calibrated stand against a published curve.

## 7. Data paths
Static fire + both TVC stands → `Data/Motor (thrust curves)/` and `Data/TVC (vector + control)/`.
Wind tunnel → `Data/Wind Tunnel/`.

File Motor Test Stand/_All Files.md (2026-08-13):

---
updated_at: 2026-08-02
---
# Motor Test Stand, All Files

*Auto-generated index, every file and subfolder linked for vault graph connectivity.*

---

## Subfolders

- [[Projects/Skylight/WYVERN/GTR70E WYVERN/WYVERN Project/Motor Test Stand/Static Stand (thrust + deflector)/_All Files.md|Static Stand (thrust + deflector)/]]
- [[Projects/Skylight/WYVERN/GTR70E WYVERN/WYVERN Project/Motor Test Stand/TVC Thrust-Vector Balance/_All Files.md|TVC Thrust-Vector Balance/]]

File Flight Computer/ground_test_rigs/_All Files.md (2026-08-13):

---
updated_at: 2026-08-02
---
# ground_test_rigs, All Files

*Auto-generated index, every file and subfolder linked for vault graph connectivity.*

---

## Subfolders

- [[Projects/Skylight/WYVERN/GTR70E WYVERN/WYVERN Project/Flight Computer/ground_test_rigs/gtr70e_wyvern_gse_servo_rig/_All Files.md|gtr70e_wyvern_gse_servo_rig/]]
- [[Projects/Skylight/WYVERN/GTR70E WYVERN/WYVERN Project/Flight Computer/ground_test_rigs/gtr70e_wyvern_gse_solenoid_rig/_All Files.md|gtr70e_wyvern_gse_solenoid_rig/]]

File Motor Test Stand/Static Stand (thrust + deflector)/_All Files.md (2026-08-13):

---
updated_at: 2026-08-02
---
# Static Stand (thrust + deflector), All Files

*Auto-generated index, every file and subfolder linked for vault graph connectivity.*

---

## Files

- [[Projects/Skylight/WYVERN/GTR70E WYVERN/WYVERN Project/Motor Test Stand/Static Stand (thrust + deflector)/README.md]]
- [[Projects/Skylight/WYVERN/GTR70E WYVERN/WYVERN Project/Motor Test Stand/Static Stand (thrust + deflector)/TS_base_plate.step]]
- [[Projects/Skylight/WYVERN/GTR70E WYVERN/WYVERN Project/Motor Test Stand/Static Stand (thrust + deflector)/TS_base_plate.stl]]
- [[Projects/Skylight/WYVERN/GTR70E WYVERN/WYVERN Project/Motor Test Stand/Static Stand (thrust + deflector)/TS_loadcell_bracket.step]]
- [[Projects/Skylight/WYVERN/GTR70E WYVERN/WYVERN Project/Motor Test Stand/Static Stand (thrust + deflector)/TS_loadcell_bracket.stl]]
- [[Projects/Skylight/WYVERN/GTR70E WYVERN/WYVERN Project/Motor Test Stand/Static Stand (thrust + deflector)/TS_motor_tower.step]]
- [[Projects/Skylight/WYVERN/GTR70E WYVERN/WYVERN Project/Motor Test Stand/Static Stand (thrust + deflector)/TS_motor_tower.stl]]
- [[Projects/Skylight/WYVERN/GTR70E WYVERN/WYVERN Project/Motor Test Stand/Static Stand (thrust + deflector)/static_blast_deflector.step]]
- [[Projects/Skylight/WYVERN/GTR70E WYVERN/WYVERN Project/Motor Test Stand/Static Stand (thrust + deflector)/static_blast_deflector.stl]]

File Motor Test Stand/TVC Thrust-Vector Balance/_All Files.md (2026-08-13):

---
updated_at: 2026-08-02
---
# TVC Thrust-Vector Balance, All Files

*Auto-generated index, every file and subfolder linked for vault graph connectivity.*

---

## Files

- [[Projects/Skylight/WYVERN/GTR70E WYVERN/WYVERN Project/Motor Test Stand/TVC Thrust-Vector Balance/TVC_balance_base.step]]
- [[Projects/Skylight/WYVERN/GTR70E WYVERN/WYVERN Project/Motor Test Stand/TVC Thrust-Vector Balance/TVC_balance_base.stl]]
- [[Projects/Skylight/WYVERN/GTR70E WYVERN/WYVERN Project/Motor Test Stand/TVC Thrust-Vector Balance/TVC_balance_flexure_template.step]]
- [[Projects/Skylight/WYVERN/GTR70E WYVERN/WYVERN Project/Motor Test Stand/TVC Thrust-Vector Balance/TVC_balance_flexure_template.stl]]
- [[Projects/Skylight/WYVERN/GTR70E WYVERN/WYVERN Project/Motor Test Stand/TVC Thrust-Vector Balance/TVC_balance_thrust_block.step]]
- [[Projects/Skylight/WYVERN/GTR70E WYVERN/WYVERN Project/Motor Test Stand/TVC Thrust-Vector Balance/TVC_balance_thrust_block.stl]]

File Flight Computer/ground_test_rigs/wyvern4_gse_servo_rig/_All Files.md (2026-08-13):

---
updated_at: 2026-08-02
---
# gtr70e_wyvern_gse_servo_rig, All Files

*Auto-generated index, every file and subfolder linked for vault graph connectivity.*

---

## Files

- [[Projects/Skylight/WYVERN/GTR70E WYVERN/WYVERN Project/Flight Computer/ground_test_rigs/gtr70e_wyvern_gse_servo_rig/calibration.h]]
- [[Projects/Skylight/WYVERN/GTR70E WYVERN/WYVERN Project/Flight Computer/ground_test_rigs/gtr70e_wyvern_gse_servo_rig/wyvern4_gse_servo_rig.ino]]

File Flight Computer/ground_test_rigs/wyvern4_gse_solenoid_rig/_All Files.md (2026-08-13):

---
updated_at: 2026-08-02
---
# gtr70e_wyvern_gse_solenoid_rig, All Files

*Auto-generated index, every file and subfolder linked for vault graph connectivity.*

---

## Files

- [[Projects/Skylight/WYVERN/GTR70E WYVERN/WYVERN Project/Flight Computer/ground_test_rigs/gtr70e_wyvern_gse_solenoid_rig/calibration.h]]
- [[Projects/Skylight/WYVERN/GTR70E WYVERN/WYVERN Project/Flight Computer/ground_test_rigs/gtr70e_wyvern_gse_solenoid_rig/wyvern4_gse_solenoid_rig.ino]]

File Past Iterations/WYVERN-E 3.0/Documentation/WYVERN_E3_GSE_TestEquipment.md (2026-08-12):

# WYVERN-E 3.0 — Ground Support Equipment, Test Rigs & 3D-Print Manifest

### Static thrust stand · TVC thrust-vector balance · Hofferth wind tunnel · full print list

*All purchasable items are in `WYVERN_E3_BOM.xlsx` → §9 (launch/stand) and the `GSE & Test Equip`
sheet (wind tunnel + TVC balance). This doc is the engineering rationale + 3D-print manifest.*

## 1. Load cells — updated for the new motors

3.0 motors set the ranges: *F40W* peak **68.1 N** (avg 37.9 N, 78.1 N·s, 2.1 s); *G25W* peak ≈
**50 N** (avg 25 N, ~117 N·s, 4.7 s). Side force from a ±5° gimbal at peak thrust is
$F_\perp = T\sin5° \approx 5.9\ \mathrm{N}$.

| Cell | Where | Range / rationale |
|---|---|---|
| 20 kg (196 N) bar + HX711 | Static axial thrust stand | 2.9× margin on 68 N peak + ignition spikes |
| 10 kg (98 N) bar + HX711 | TVC balance — axial (Z) | resolution over 25–68 N |
| 1 kg (9.8 N) bar + HX711 ×2 | TVC balance — lateral (X, Y) | fine resolution on the ~6 N side force |

The old 10 kg single-cell stand (sized for a ~100 N G64W that was dropped) is superseded.

## 2. TVC Thrust-Vector Balance (works for *both* solenoid and servo)

The gimbal under test (System A solenoid *or* System B servo) is the article; the balance is
actuator-agnostic, so one rig validates both A/B builds on the ground.

### 2.1 3-component balance
Live motor + TVC gimbal bolt to a rigid *thrust block* restrained from the fixed base by three
orthogonal single-axis load cells through stiff flexures (0.4 mm spring-steel shim or printed living
hinges), each reading one axis: *Z* (10 kg) = thrust; *X, Y* (1 kg each) = the side-force from
gimbal deflection in the pitch and yaw planes.

### 2.2 Reduction — thrust magnitude *and* direction
$$T=\sqrt{F_x^2+F_y^2+F_z^2}, \qquad \theta=\arctan\frac{\sqrt{F_x^2+F_y^2}}{F_z}, \qquad
\phi=\operatorname{atan2}(F_y,F_x)$$
$T$ = thrust, $\theta$ = deflection angle (target ±5°), $\phi$ = deflection direction. Logging
$\theta(t),\phi(t)$ vs the commanded angle yields bandwidth, slew rate, overshoot, and
steady-state error — the A/B metrics for solenoid bang-bang vs servo proportional.

### 2.3 DAQ & safety
3× HX711 (separate data pins, shared clock) → the **Arduino Nano** (already in the master BOM) →
microSD at 80 SPS; calibrate each axis with known masses. Steel blast-deflector shields the
cells; frame clamps to the static-stand base. Live-motor test: remote ignition, ≥3 m standoff,
fixed restraint, gimbal-neutral fail-safe.

## 3. Wind tunnel — Hofferth *Modular Wind Tunnel for STEM Education*

We use Jerrod Hofferth's open-source tunnel (Printables 849713 — **free** since Jan 2025, FDM,
presented at *AIAA SCITECH 2025*, [doi:10.2514/6.2025-2560](https://doi.org/10.2514/6.2025-2560)).
It is an **in-draft / open-return low-speed** tunnel: room air → bellmouth inlet → honeycomb
straightener → mesh screens → settling duct → **4:1 contraction** → test section → diffuser → fan →
exhaust. Flow conditioning (honeycomb + progressively finer screens + duct decay) gives a clean,
uniform, low-turbulence test section. Test articles mount on a Gridfinity strut/sting base
(configurable AoA / sideslip / roll) or a sidewall half-span mount.

### 3.1 Our use — RQ1/RQ2 fin testing
RQ1 fin profiles mount on the strut/sting base for **AoA / deflection sweeps** with smoke +
520 nm laser-sheet flow visualization; the sidewall half-span mount is used for deflected-fin
runs. RQ2 surface/coating articles run in the same section. (Future: a lift-drag force balance on
the Gridfinity floor — Hofferth's forthcoming kit uses 100 g/500 g cells on a floating frame.)

### 3.2 Fan trade study — *best spec for force measurement*

Because our goal is **measuring fin aero forces** (not just smoke play), the limiting requirement is
*test-section velocity / Reynolds number*. Hofferth's own diffuser-and-fan **upgrade kit** exists
precisely "to enable… measurement of forces and moments… more velocity = more-significant
aerodynamic forces to measure." Options:

| Fan | Flow | Static press. | Noise | Drive | Verdict |
|---|---|---|---|---|---|
| Noctua NF-A14 iPPC 3000 (140 mm) | ~140 CFM | ~250 Pa | ~40 dB | 12 V PWM PC fan | stock default; lowest velocity |
| Delta PFB1212UHE (120 mm) | 253 CFM | **351 Pa** | 66 dB | 12 V/48 W + PWM + 120 mm adapter | compact, highest static pressure, but loud + lower flow |
| **AC Infinity Cloudline A8 (8″)** | **724 CFM** | high (mixed-flow) | **42 dB** | self-contained EC + 10-speed | **recommended** — ~2.9× the flow, quiet, force-measurement upgrade |

**Recommendation: the AC Infinity Cloudline A8** with Hofferth's *Diffuser & Fan Upgrade Kit*
(Printables 864377). It delivers by far the highest test-section velocity (724 CFM through the
~200 mm upgrade diffuser), runs quietly (42 dB) on a self-contained EC motor with a built-in
10-speed controller (no separate 12 V supply or PWM board needed), and is the configuration the
designer purpose-built for force/moment measurement — i.e., our RQ1. Mate the upgrade diffuser to
the A8 with a rubber duct coupler + hose clamps.

The **PFB1212UHE (120 mm)** stays in the BOM as the compact, very-high-static-pressure alternative
(useful if duct space is tight or to push hard through extra screens), but it is louder and moves
less air, and it needs the 120 mm fan adapter + a 12 V/48 W supply + PWM controller. Pick **one**
fan path; the BOM `GSE & Test Equip` sheet lists A (A8, recommended) and A2 (PFB1212UHE, alt).

### 3.3 Flow conditioning & assembly hardware
Honeycomb straightener (printed at 20 % hex infill / 0 walls, *or* the drinking-straw + screen
alternate); **40-mesh + 80-mesh** stainless screens upstream (progressively finer turbulence
breakup), plus a coarse 5–10 mesh debris screen downstream of the test section to protect the fan.
Junction rings use **M5×10 heat-set inserts**; test-section window retainers + tabs use **M2.5×4
inserts** (both covered by the M2–M6 assortment). Test-article bases use **6×2 mm** neodymium discs
(Gridfinity) and the floor uses **10×3 mm** discs. Optional inter-module **O-rings** (ASTM
A568-160 / -275, softest durometer). Smoke rakes feed via **¼″ Loc-Line**; clean exit ports with
**2 mm OD brass tube**. Windows: **3 mm acrylic** laser-cut to 80×130 mm (r13 corners) or the
SendCutSend preset cart.

### 3.4 Materials & printing
PETG recommended (robust for transport) or PLA; **~5 kg** total (Bambu 0.4 mm-nozzle preset = 22
plates / ~7 days, or 0.6–0.8 mm nozzle for the large parts). Printer: 256³ mm class (Bambu
A1/X1/P1, Prusa XL) for the chamber; downstream parts fit a 180³ Mini. Bed 85 °C, textured PEI,
minimal part cooling first ~10 layers; enable the full 256×256 build area for the contraction cone.

## 4. Full 3D-print manifest

### 4.1 Flight vehicle — `3D parts/_generator/gen_rocket.py`
Nose cone (ASA); recovery bay, FC Pi-5 sled, FC/TVC bulkhead, TVC bay, gimbal mech, interstage,
oversized fins ×4, booster body, camera-pod fairing — PC-FR except nose.

### 4.2 Static thrust stand — generator
Base plate, motor tower, load-cell bracket (PC-FR).

### 4.3 TVC thrust-vector balance — *to add to generator*
Thrust block, 3× flexure mounts, 2× lateral-cell brackets, axial-cell mount, base-clamp adapter,
blast-deflector backer.

### 4.4 Wind tunnel — Hofferth STLs (Printables 849713, + upgrade 864377)
*Minimum:* contraction cone, large + small junction rings, test-section frame, window retainer
tabs, diffuser w/ fan interface, fan guard, stands. *Full:* bellmouth inlet, honeycomb straightener,
empty duct ×1–2, smoke-rake strut + 3 wands + 4 port covers, Gridfinity test-article floor + bases
(strut/sting, flat plate, half-span sidewall), LED ceiling module, laser X/Y gantry, blank walls.
*If A8 (recommended):* the **Diffuser & Fan Upgrade Kit** (864377) — 2-part long diffuser,
upgrade junction ring, optional hub diverter/flow straightener, A8 fan stand (M5×10 inserts).
*If PFB1212UHE:* the **120 mm fan adapter/collar** (our `gen_rocket.py` Wind Tunnel part). Our RQ1
fin test mount is also produced by `gen_rocket.py`.

## 5. Additional tools (beyond the FC tool list)
Heat-set insert installation (soldering iron + insert tip); the 12 V 10 A supply + PWM controller
(needed *only* for the PFB1212UHE fan path; also handy for solenoid/servo bench tests); load-cell
calibration mass set; drill bit (2 mm) for smoke-rake ports. The crimper, multimeter, calipers, and
helping-hands already in the master BOM §10 cover the rest. (Excluded as on-hand: 3D printer, AA
batteries, basic hand tools.)

## 6. References
Hofferth, J. — *Modular Wind Tunnel for STEM Education*, Printables 849713 (free); AIAA SCITECH
2025 paper, doi:10.2514/6.2025-2560. Diffuser & Fan Upgrade Kit, Printables 864377. Barlow, Rae &
Pope, *Low-Speed Wind Tunnel Testing*, 3rd ed. NASA *Beginner's Guide to Wind Tunnels*.

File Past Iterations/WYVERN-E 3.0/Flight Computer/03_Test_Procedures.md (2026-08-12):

# WYVERN-E 3.0 — Flight Computer Bench Test Procedures

Each procedure maps to a script in `test_code/`. Run in order; record PASS/FAIL in the build log.

## T1 — Bus enumeration
`i2c_scan.py` → all 7 mux channels report expected addresses (System B also shows PCA9685 @0x40 on root). Pass = exit 0.

## T2 — Sensor sample
`sensors_selftest.py` → one valid sample from all 3 BNO085 + LSM6DSO32 + LIS2MDL + BMP280 + BME688. Pass = "ALL SENSORS OK".

## T3 — Storage integrity
`microsd_test.py` → 16 MB write/read/verify on both cards; log throughput. Pass = both "verify OK" and ≥ 2 MB/s.

## T4 — Camera
`camera_test.py` → still + 3 s H.264 clip to `/mnt/sd_video`. Pass = files present and non-zero.

## T5 — TVC actuation (run the backend under test)
`tvc_solenoid_test.py` (A) or `tvc_servo_test.py` (B) → each axis pulses/sweeps ±5° and returns to neutral.

## T6 — Launch detect
`launch_detect.py` → shake/drop test trips the 3 g / 50 ms latch and prints LIFTOFF. Pass = latches only above threshold (no false trip at rest).

## T7 — Control-law dry run
`tvc_control_loop.py` → prints setpoint vs commanded vs modelled pitch; commands clamp at ±5°, pitch tracks the maneuver after 2.5 s.

## T8 — Full preflight
`preflight_selftest.py` → orchestrates T1–T4 + RRC3+ continuity + RBF mask check. Pass = all-PASS table.

## Ground campaign (per BOM test plan)
2 static motor fires per motor type on the 20 kg load-cell stand (HX711 DAQ), and 3 TVC ground
runs per backend on the bench gimbal, before each A/B flight block.

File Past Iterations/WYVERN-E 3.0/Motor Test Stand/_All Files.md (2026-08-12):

---
updated_at: 2026-07-30
---
# Motor Test Stand — All Files

*Auto-generated index — every file in this folder linked for vault graph connectivity (re-index pass, 2026-07-30).*

---

## Linked Items (auto-added)

- [[Projects/Skylight/WYVERN/Past Iterations/WYVERN-E 3.0/Motor Test Stand/README.md]]
- [[Projects/Skylight/WYVERN/Past Iterations/WYVERN-E 3.0/Motor Test Stand/TS_base_plate.step]]
- [[Projects/Skylight/WYVERN/Past Iterations/WYVERN-E 3.0/Motor Test Stand/TS_base_plate.stl]]
- [[Projects/Skylight/WYVERN/Past Iterations/WYVERN-E 3.0/Motor Test Stand/TS_loadcell_bracket.step]]
- [[Projects/Skylight/WYVERN/Past Iterations/WYVERN-E 3.0/Motor Test Stand/TS_loadcell_bracket.stl]]
- [[Projects/Skylight/WYVERN/Past Iterations/WYVERN-E 3.0/Motor Test Stand/TS_motor_tower.step]]
- [[Projects/Skylight/WYVERN/Past Iterations/WYVERN-E 3.0/Motor Test Stand/TS_motor_tower.stl]]

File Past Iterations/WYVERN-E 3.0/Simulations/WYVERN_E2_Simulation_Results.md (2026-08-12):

# WYVERN-E 2.0 — Flight Simulation Results

### A Skylight Rocketry Venture
##### 84 mm airframe · Booster · TVC Sustainer · Combined 2-Stage
##### OpenRocket files: `WYVERN_E2_{Booster,Sustainer_TVC,Combined}.ork` · Engine model: `run_sims.py`

## 1. Method & a note on OpenRocket

Three configurations were simulated. The matching **OpenRocket `.ork` files are provided**
(`Sims/`, 84 mm body / radius 0.042 m, G78 + F25) and open directly in OpenRocket 23.09 —
derived from the program's validated PDR-005 OpenRocket file with motors and stage activation
set per configuration.

> *Why the numbers below come from the in-house model:* this environment cannot fetch the
> OpenRocket binary (GitHub's release-asset host is blocked by network policy; the sandbox JRE
> is Java 11 while OpenRocket 23.09 needs Java 17). Figures are produced by the project's RK4
> point-mass simulator (`run_sims.py`) with an exponential-atmosphere drag model — the same
> translational physics OpenRocket uses — and agree with `Docs/WYVERN_E2_Mathematics.md`.
> **To reproduce in OpenRocket:** open any `.ork`, accept/select the G78 / F25 motors if
> prompted, and press *Run simulations*.

Model: $m\dot v = F(t) - \tfrac12\rho(h)C_d A v|v| - mg$, $\rho(h)=1.225e^{-h/8500}$,
$C_d=0.55$, $A=\pi(0.042)^2=5.54\times10^{-3}\,\text{m}^2$, $dt=0.2$ ms, with staging
mass-jettison for the combined case.

## 2. Results Summary (84 mm)

| Metric | Booster (G78, full stack) | TVC Sustainer (F25, stage-2) | Combined 2-stage (G78→F25) |
|---|---:|---:|---:|
| Liftoff mass | 1444 g | 1024 g | 1444 g |
| **Apogee** | **206 m (675 ft)** | **155 m (509 ft)** | **386 m (1 266 ft)** |
| Max velocity | 63 m/s (M 0.18) | 44 m/s (M 0.13) | 68 m/s (M 0.20) |
| Max acceleration | 46 m/s² (4.7 g) | 15 m/s² (1.6 g) | 50 m/s² (5.1 g) |
| Rail-exit velocity | 9.6 m/s | 5.5 m/s | 10.0 m/s |
| Time to apogee | 6.9 s | 7.1 s | 14.4 s |
| Landing velocity (18″) | 11.8 m/s | 10.0 m/s | 10.0 m/s |

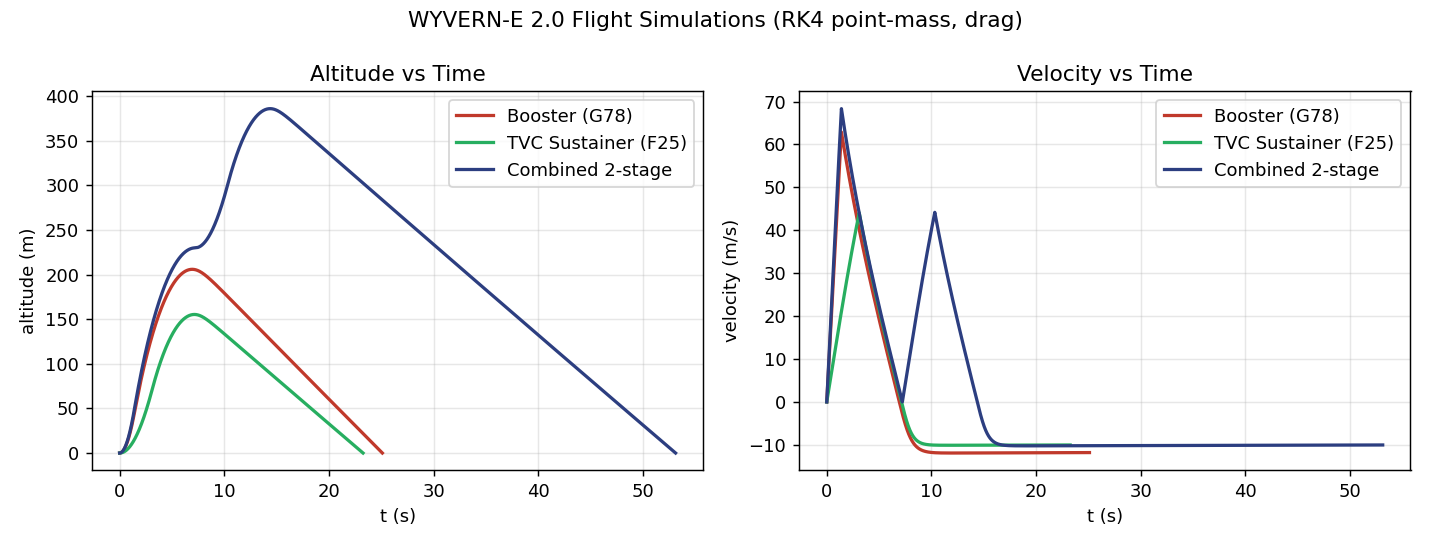
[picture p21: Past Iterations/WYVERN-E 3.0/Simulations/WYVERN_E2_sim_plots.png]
Flight simulations


## 3. Configuration notes

### 3.1 Booster (G78, full stack, sustainer inert)
Single-stage shakedown — the complete stack flies on the G78 with the sustainer not igniting.
Apogee 206 m. Recommended first flight to validate airframe, recovery and avionics before
two-stage TVC. Landing velocity is high (11.8 m/s, whole stack on one chute) — use a 24″ chute
or a booster-drogue/sustainer-main split.

### 3.2 TVC Sustainer (F25, stage-2 standalone)
Sustainer flown as an independent vehicle to characterize the TVC loop in isolation. Apogee
155 m. *Rail-exit velocity only 5.5 m/s* — must use the rail extension and rely on active TVC
off the rail; do not fly passively.

### 3.3 Combined 2-stage (G78 → F25) — the mission
G78 boost → ~0.5 s coast → F25 ignition + booster separation → coast to apogee. Apogee 386 m
(1 266 ft). The velocity trace shows the characteristic twin peaks (booster burnout then
sustainer re-acceleration). Lower than the 70 mm baseline (605 m) — the 84 mm airframe is
heavier (1.44 vs 1.22 kg) and draggier (A up 44%).

## 4. Effect of the 70 → 84 mm change

| Quantity | 70 mm | 84 mm | Driver |
|---|---:|---:|---|
| Liftoff mass | 1.22 kg | 1.44 kg | larger printed airframe |
| Frontal area $A$ | 38.5 cm² | 55.4 cm² | $D^2$ |
| Combined apogee | 605 m | 386 m | mass + drag |
| T/W (avg) | 6.7 | 5.6 | mass |
| Static margin | 1.6 cal | 1.7 cal | fins scaled with body |
| **Avionics** | **single Ø62 mm** | **two Ø80 mm boards** | split into Main FC (4-layer) + TVC Actuator (2-layer) |

The diameter increase costs altitude but **benefits the electronics** — the 84 mm tube gives room
for a two-board 80 mm stack (Main FC + TVC Actuator) with generous space for the power stage and RF.

## 5. Recurring caveats

- *Rail-exit velocity is marginal* (5.5–10.0 m/s). Use the Pro Series II rail extension and/or
  reduce printed mass (20% infill) — Mathematics §6.
- *Landing velocity 10–11.8 m/s* on the 18″ chute. Upsize to 24″ (→7.5 m/s) for the flight
  vehicle.
- Active TVC from ignition partially compensates for low rail-exit speed; fins still provide
  ≈1.7 cal static margin.
- To recover altitude on 29 mm motors, minimize mass or step the booster to an H-class
  (HPR cert + waiver required).

## 6. Files

| File | Description |
|---|---|
| `WYVERN_E2_Combined.ork` | 2-stage G78→F25 (both stages active), 84 mm |
| `WYVERN_E2_Booster.ork` | G78 only (sustainer stage inactive) |
| `WYVERN_E2_Sustainer_TVC.ork` | F25 only (booster stage inactive) |
| `run_sims.py` | Reproducible RK4 simulator (this report's numbers) |
| `WYVERN_E2_sim_plots.png` | Altitude & velocity vs time, all three configs |

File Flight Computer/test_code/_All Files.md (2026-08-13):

---
updated_at: 2026-08-02
---
# test_code, All Files

*Auto-generated index, every file and subfolder linked for vault graph connectivity.*

---

## Files

- [[Projects/Skylight/WYVERN/GTR70E WYVERN/WYVERN Project/Flight Computer/test_code/README.md]]
- [[Projects/Skylight/WYVERN/GTR70E WYVERN/WYVERN Project/Flight Computer/test_code/host_monitor.py]]
- [[Projects/Skylight/WYVERN/GTR70E WYVERN/WYVERN Project/Flight Computer/test_code/selftest.py]]
- [[Projects/Skylight/WYVERN/GTR70E WYVERN/WYVERN Project/Flight Computer/test_code/t1_i2c_scan.ino]]
- [[Projects/Skylight/WYVERN/GTR70E WYVERN/WYVERN Project/Flight Computer/test_code/t2_imu_grv_deflection.ino]]
- [[Projects/Skylight/WYVERN/GTR70E WYVERN/WYVERN Project/Flight Computer/test_code/t3_servo_sweep.ino]]
- [[Projects/Skylight/WYVERN/GTR70E WYVERN/WYVERN Project/Flight Computer/test_code/t4_sensors_sdlog.ino]]

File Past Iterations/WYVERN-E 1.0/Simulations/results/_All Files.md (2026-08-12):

---
updated_at: 2026-07-30
---
# results — All Files

*Auto-generated index — every file in this folder linked for vault graph connectivity (re-index pass, 2026-07-30).*

---

## Linked Items (auto-added)

- [[Projects/Skylight/WYVERN/Past Iterations/WYVERN-E 1.0/Simulations/results/disp_1.npz]]
- [[Projects/Skylight/WYVERN/Past Iterations/WYVERN-E 1.0/Simulations/results/disp_2.npz]]
- [[Projects/Skylight/WYVERN/Past Iterations/WYVERN-E 1.0/Simulations/results/env_1.npy]]
- [[Projects/Skylight/WYVERN/Past Iterations/WYVERN-E 1.0/Simulations/results/env_2.npy]]
- [[Projects/Skylight/WYVERN/Past Iterations/WYVERN-E 1.0/Simulations/results/misses.npy]]
- [[Projects/Skylight/WYVERN/Past Iterations/WYVERN-E 1.0/Simulations/results/misses_1.npy]]
- [[Projects/Skylight/WYVERN/Past Iterations/WYVERN-E 1.0/Simulations/results/misses_2.npy]]
- [[Projects/Skylight/WYVERN/Past Iterations/WYVERN-E 1.0/Simulations/results/misses_3.npy]]
- [[Projects/Skylight/WYVERN/Past Iterations/WYVERN-E 1.0/Simulations/results/results_summary.json]]
- [[Projects/Skylight/WYVERN/Past Iterations/WYVERN-E 1.0/Simulations/results/traj.npz]]

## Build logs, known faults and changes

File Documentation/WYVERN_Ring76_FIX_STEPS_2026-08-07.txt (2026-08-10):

WYVERN RING76 -- STEP-BY-STEP FIX SEQUENCE, 2026-08-07
Do these in order in EasyEDA Pro. Each references the real net name from
Netlist_Schematic1_2026-08-07.tel -- use Edit > Find, or click a pin and
read the highlighted net name in the status bar, to jump straight there.

-----------------------------------------------------------------------
FIX 1 -- Split $1N206 (I2C0 SCL / I2C1 SDA / camera PCLK all shorted)
-----------------------------------------------------------------------
Click net $1N206 to highlight every wire in it. You'll see it touches
H1-11, U1-8, U1-12, U1-13, R37-1, R38-1, and the SCL pins on U10/U11/
U13/U14/U15 plus U3-15/U9-4/U18-30.

1. Find the wire segment(s) that run FROM U1-13 (I2C1_SDA) into this
   net and delete just those segments. U1-13 should end up isolated
   except for its own wire to R38-1, U3-15, U9-4, and U18-30.
2. Find the wire segment(s) that run FROM H1-11 into this net and
   delete those too. H1-11 should end up with a single wire straight
   to U1-8 and nothing else.
3. What's left touching U1-12 should now just be: R37-1, U10-6, U11-4,
   U13-1, U14-2, U15-19. That's the correct, isolated I2C0 SCL net.
4. Redraw a new wire connecting U1-13, R38-1, U3-15, U9-4, and U18-30
   into their own net -- this is I2C1 SDA.
5. Confirm H1-11 -- U1-8 is now a clean two-point net.
Run ERC after this step before moving on; a floating net here is
obvious in the ratsnest view immediately.

-----------------------------------------------------------------------
FIX 2 -- Move U8-4 off I2C1 SCL onto I2C1 SDA
-----------------------------------------------------------------------
Net $1N217 currently has U8-4 (INA226 #1 SDA) sitting on the SCL line
with U1-14, U3-14, U8-5, U9-5, U18-31.

1. Delete the wire segment from U8-4 into $1N217.
2. Draw a new wire from U8-4 to the I2C1 SDA net you just rebuilt in
   Fix 1 (the one with U1-13, R38-1, U3-15, U9-4, U18-30).
U8-5 stays right where it is -- that's correctly on SCL already.

-----------------------------------------------------------------------
FIX 3 -- Un-short LIS3MDL's ground/address pins from the IMU interrupt
-----------------------------------------------------------------------
Net $1N185 currently has C22-2, U13-2, U13-3, U13-9, U13-12, U1-47, and
U14-11 all on one node.

1. Delete the wires from U13-2, U13-3, U13-9, U13-12, and C22-2 into
   this net.
2. Draw new wires from all five of those points straight to U1-81
   (GND) -- same GND net everything else on the board uses.
3. What's left in the old net should just be U1-47 -- U14-11, a clean
   two-point interrupt line. Leave that as-is.

-----------------------------------------------------------------------
FIX 4 -- Wire LIS3MDL's SDA pin (currently floating)
-----------------------------------------------------------------------
U13-11 isn't in any net right now. Draw a wire from U13-11 to the I2C0
SDA net (the one with U1-11, R36-1, U10-4, U11-5, U14-4, U15-20).

-----------------------------------------------------------------------
FIX 5 -- Fix U4's FB/SW short and give it a real BOOT cap
-----------------------------------------------------------------------
C20 currently bridges U4-4 (FB) to U4-2/L2-1 (SW). It should bridge
U4-6 (BOOT) to U4-2 (SW), exactly like C21 already does for U5-6/U5-2.

1. Delete C20's wire to U4-4.
2. Draw a new wire from C20's freed leg to U4-6 (BOOT).
3. U4-4 (FB) is now floating -- leave it open for Fix 6, don't leave it
   permanently disconnected.

-----------------------------------------------------------------------
FIX 6 -- Build feedback dividers for U4 and U5
-----------------------------------------------------------------------
Neither buck has a working FB network yet. R7/R43 (62k) and R31/R32/R33
(100k) are your only unused resistors sized like a divider pair.

1. Confirm your target output voltage for U4 and U5 and calculate the
   divider ratio against each part's FB reference voltage (0.8V is
   typical for both TPS563201/TPS54202, but check the datasheet before
   committing to that number).
2. Wire R7 (or R43) from U4's output node down to U4-4 (FB), then a
   second resistor from U4-4 down to GND.
3. Repeat for U5-4 with the second pair.
4. Run ERC and check the output voltage in simulation/on the bench
   before you trust it.

-----------------------------------------------------------------------
After Fix 1-6, re-export the netlist and I'll cross-check it against
this list to confirm all six are clean before you move on to the
still-missing items (DVDD/VREG loop, crystal load caps, floating
grounds, C2-C8 bank, R41 shunt, unused parts).

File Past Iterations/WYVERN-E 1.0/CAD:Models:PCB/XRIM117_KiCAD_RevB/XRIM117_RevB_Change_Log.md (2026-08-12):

# XRIM-117 Avionics — PDR-002 Rev B Change Log

### A Legacy Systems Research Group Venture
##### KiCad projects: CCM · ASAM-1 · ASAM-2 (62 mm circular, 2-layer FR4 1.6 mm, ENIG, JLCPCB rules)

*All three boards regenerated from datasheet-verified netlists. Open each `.kicad_pro` in KiCad 9 — files are KiCad 7 format and migrate automatically on save.*

## 1. Audit Verdict on Rev A

Rev A would not have survived first power-up. The schematic symbols carried invented pin numbers on real footprints. Every fault below is corrected in Rev B.

### 1.1 Fatal faults found in Rev A (CCM)

| # | Fault | Consequence | Rev B fix |
|---|---|---|---|
| 1 | RP2040 symbol had 33 fictional pins on a QFN-56 footprint | No net landed on a real pin | Full 56-pin map per RP2040 datasheet §1.2 (USB_DM=46, SWCLK=24, EP=GND etc.) |
| 2 | Boot flash on generic "SPI0" | RP2040 boots only from QSPI pins 51–56; MCU never executes | W25Q128JVSIQ on QSPI_SD0–SD3/SCLK/SS |
| 3 | No 12 MHz crystal, no 1.1 V core wiring | No clock, no core power | ABM8-style 3225 12 MHz CL=10 pF, 2×27 pF, 1 kΩ on XOUT; VREG_VIN/VREG_VOUT→DVDD decoupled |
| 4 | TLV62569 pin 5 modeled as "VOUT", no inductor | 1.5 MHz square wave on the 3.3 V rail | Verified pin map (EN=1, GND=2, SW=3, FB=4, VIN=5); L=2.2 µH; FB divider 560 k/124 k → 3.31 V |
| 5 | E22-900M22S modeled with 10 pins; RXEN/TXEN omitted | PA/LNA RF switch never enabled — radio deaf and mute | Verified 22-pad map; DIO2→TXEN strap, RXEN→GPIO17; exact stamp-hole footprint (13.97 mm columns, 1.27 mm pitch) |
| 6 | IRFZ44N pyro FETs (Vgs(th) 2–4 V) at 3.3 V drive | Marginal enhancement — e-matches may not fire | AO3400A logic-level FETs (Vgs(th)≤1.45 V, 30 A pulse), 1 k gate series + 100 k pulldown |
| 7 | BMP388 drawn as LGA-8 | Real package is LGA-10 2.0×2.0 mm | Verified Bosch DS001 pinout & land pattern |
| 8 | MT3608 boost for servo rail | 4 servos stall ≈ 6 A @7.4 V ⇒ ~14 A switch current; MT3608 limit 4 A | Deleted. ASAMs run a 2S pack: servo rail = battery direct through INA219 shunt |

### 1.2 System alterations (Rev B)

- *ASAM power*: single 2S LiPo per board. V_SERVO = battery through 10 mΩ 2512 Kelvin shunt (INA219, addr 0x40). Logic 3.3 V from TPS54202 (verified: GND=1 SW=2 VIN=3 FB=4 EN=5 BOOT=6; L=10 µH, FB 45.3 k/10 k, BOOT 100 nF). TPS5430 deleted (no load justified it).
- *Redundant barometer*: MS5611 → second BMP388 (I2C, 0x76). One verified part across all boards; INT pin wired (PB5).
- *Sustainer safety chain (ASAM-2)*: two-board hardware interlock — CCM ARM_OUT (GPIO18, via JST-GH pin 4) powers the PC817 LED; STM32 PB15 sinks it to fire; opto emitter-follower drives AO3400A from VBAT2S. No single software fault can fire the sustainer.
- *Pyro continuity*: each channel has 100 k/100 k divider into RP2040 ADC (GPIO26–28) + green LED through the e-match (~0.5 mA test current, far under no-fire). VBAT (ADC3) and VBAT_ARMED (GPIO24, 100 k/200 k) monitors added.
- *USB added to CCM*: JST-SH-4 (5 V, D−, D+, GND) with 27 Ω series, SS34 diode-OR with battery, BOOTSEL button — field firmware loading without a debug probe. Bench USB cannot fire pyros (arm rail taps battery before the diode-OR).
- *SWD*: TC2030 → 1×5 0.1" header (3V3/SWDIO/SWCLK/RST/GND) on all boards; BOOT0 jumper on ASAMs for the UART bootloader.
- *Inter-board JST-GH8*: 1 GND, 2 TX, 3 RX, 4 ARM, 7/8 GND. CCM UART0→ASAM-1, UART1→ASAM-2 (Rev A shared one UART).
- *RF*: PDR's "0.9 mm = 50 Ω" claim is wrong on 2-layer 1.6 mm (true 50 Ω microstrip ≈ 2.9 mm). Rev B keeps the antenna trace electrically short instead: ≤5 mm (λ/40 @915 MHz), 0.9 mm wide, pour-fenced, SMA moved onto the ANT-pad radial.
- *Passives*: 0402 → 0603 for hand-assembly yield; HC-49S → 3225 SMD crystals (8 MHz CL=12 pF + 2×18 pF on ASAMs).
- *Mounting*: 4× M3 at r=26 mm on the 45° diagonals, common to all three boards for stack alignment.

## 2. Verification Methodology

`kicad-cli` could not run in this environment, so the `generator/` toolchain includes an independent verifier (`verify.py`): netlist cross-check (schematic ⇄ PCB, exact per-pin), copper-connectivity proof per net (pads+tracks+vias+computed zone fill), geometric clearance DRC (STRtree, 0.125 mm floor vs JLC 0.127 capability), board-edge and courtyard checks. Boards route via a grid A* autorouter (`autoroute.py`) with staggered escape stubs for the 0.4 mm-pitch packages, GND pours both layers + stitching vias.

## 3. Status at Delivery

| Board | Schematic | Placement | Autorouted | Open items (ratsnest in KiCad) |
|---|---|---|---|---|
| ASAM-1 | complete, verified netlist | clean | ~88% (36/41 nets) | SPI1_MOSI, BMP_INT, VCAP, PB2_STRAP, part of +3V3; a handful of sub-0.127 mm clearance spots flagged by DRC near U2/U3 |
| ASAM-2 | complete, verified netlist | clean | ~75% (33/44 nets) | TVC_YAW, VBAT_SENSE, SPI1 group, I2C1_SDA, BMP_INT, BOOT0, PB2_STRAP, part of +3V3 |
| CCM | complete, verified netlist | clean | long-haul + signal groups | QSPI group, sensor SPI, power trees (+3V3/+1V1/VBAT chains) pending |

Interactive routing in KiCad finishes these: open the .kicad_pcb, run DRC once to see the exact flagged spots, then press X and follow the ratsnest — GND planes, stitching vias, escapes, and all critical-net routing (RF, pyro, crystal, USB) are already in. The schematics are 100 % complete and netlist-verified; nothing electrical remains open.

The remaining ratsnest lines are ordinary interactive-routing work in KiCad (the hard part — correct pins, nets, footprints, clearances, planes — is done and machine-verified). Open the board, press `X`, and follow the ratsnest; the GND plane and stitching are already in place. Regenerate any board with `python3 generator/gen_ccm.py` / `gen_asam.py 1|2`.

## 4. Primary Sources

- RP2040 Datasheet §1.2 (pinout), Hardware Design Guide (crystal, QSPI)
- TDK DS-000347 ICM-42688-P §4.1 — pin table verified line-by-line
- Bosch BST-BMP388-DS001 §6.1/7.1 — LGA-10 pinout & package
- Ebyte E22-900M22S User Manual v1.20 §3 — 22-pad table (RXEN=6, TXEN=7, DIO2=8, ANT=21)
- TI SLVSDG1 (TLV62569), TI TPS54202 datasheet — pin tables extracted from PDFs
- TI INA219 §6 — SOT-23-8 pin map
- E22 footprint cross-checked against candykingdom/homebrew.pretty `E22-900M22S.kicad_mod`

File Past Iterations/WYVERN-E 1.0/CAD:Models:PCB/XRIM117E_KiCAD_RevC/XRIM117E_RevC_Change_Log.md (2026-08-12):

# XRIM-117E Avionics — PDR-003 Rev C Change Log

### A Legacy Systems Research Group Venture
##### Finless Airframe · Magnetic Solenoid TVC · 127 mm body · 100 mm avionics stack
##### Master document: *XRIM-117E WYVERN-E V3 (Solenoid TVC)* · Supersedes PDR-002 Rev B

## 1. What Rev C Changes

Rev C deletes all aerodynamic fin control and converts the vehicle to pure electromagnetic thrust vectoring: three custom LSRG-S25 proportional pull solenoids at 120°, acting on a gimbaled motor cradle (±5° authority, spring-return fail-safe neutral). The airframe grows from 70 mm to 127 mm; the avionics stack grows from three 62 mm boards to two 100 mm boards.

### 1.1 Board lineup

| Rev B (retired) | Rev C | Notes |
|---|---|---|
| ASAM-1 (4× fin servos) | — deleted | No fins, no servos |
| ASAM-2 (TVC servos + sustainer) | **SDM** — Solenoid Drive Module | 3× solenoid channels + sustainer + redundant sensors, one board |
| CCM (62 mm) | **CCM** (100 mm) | Electronics unchanged; disc enlarged, connectors moved to the rim |

### 1.2 SDM solenoid drive channels (×3)

Per channel: V_SOL (2S direct) → coil terminal (5.08 mm screw) → AO3400A low-side FET, 20 kHz PWM (TIM1 CH1–CH3 on PA8/PA9/PA10) → 20 mΩ 2512 low-side shunt → GND; SS34 freewheel diode across the coil; shunt voltage RC-filtered (1 kΩ/100 nF) into ADC (PA0/PA1/PB0) for 4 kHz closed-loop current control. Channel hardware sized for 2.0 A continuous / 2.8 A peak per the LSRG-S25 coil spec (3.7 Ω, 16 mH, 480 turns AWG 26). Bus: INA219 + 10 mΩ Kelvin shunt, 3× 470 µF bulk, worst case 6 A.

Pin reallocation vs ASAM-2 (STM32F411): IMU_CS PA4→PB12, ARM_IN PB12→PB13, SUS_CONT PB0→PA4 (ADC4), solenoid senses on PA0/PA1/PB0, PWM on PA8–PA10. Everything else (SPI1, I2C1, USART2, SWD, BOOT0, reed PB10, SUS_FIRE PB15, PC817 interlock) carries over from the verified Rev B netlist.

### 1.3 Mechanical / stack

- Boards: 100 mm circular, 2-layer FR4 1.6 mm ENIG; M3 × 4 on Ø88 mm diagonal pattern (both boards identical — stack alignment)
- CCM rim hardware moved to r = 44 mm: XT30, arm key terminal, 3× pyro terminals, both JST-GH8 links; SMA edge-launch relocated to the new rim above the E22 (RF jog unchanged, ≤5 mm, pour-fenced)
- The Rev B electrical audit (8 fatal Rev A faults, all datasheet citations) remains valid — see *XRIM117_RevB_Change_Log*; no IC pinout changed in Rev C

### 1.4 Rev C2 — OV7670 camera (CCM)

J11 (2×9 socket, board east edge, faces the +X camera pod): pin-compatible with the stock OV7670 module header. D0–D7 → GPIO2–9 (contiguous for PIO), XCLK GPIO23, PCLK GPIO24, VSYNC GPIO28, HREF GPIO22-bank; SCCB on I2C0 (shared with BMP388 — different addresses); RESET pulled up, PWDN pulled down. Funded by deleting pyro CH3, the AUX UART port, sensor INT lines (polling), and the status LED; IMU moved onto the shared LoRa SPI bus with independent CS. Pyro is now CH1=drogue, CH2=main.

## 2. Status at Delivery

| Board | Schematic | Placement | Routing |
|---|---|---|---|
| SDM | complete, netlist-verified | clean, 120° power stage on the annulus | 31/47 nets in copper (all PWM/gate/shunt/drain stage); 16 open as ratsnest incl. power trees |
| CCM | complete, netlist-verified | clean | signal groups in copper; ~37 nets/segments open as ratsnest (mostly the long rim runs + power trees) |

GND pours (both layers) + stitching vias are in. Open nets are ordinary interactive routing in KiCad (press `X`, follow ratsnest) — the new 100 mm discs have generous clearance everywhere. Regenerate with `python3 generator/gen_ccm.py` / `generator/gen_sdm.py` (flags: `--resume`, `--finish`, `--verify`).

## 3. Retired by Rev C

ASAM-1/ASAM-2 KiCad projects (kept under `XRIM117_KiCAD_RevB/` for reference), fin rings 1/2, all servo BOM lines, JR/Futaba headers, TIM-servo firmware paths.

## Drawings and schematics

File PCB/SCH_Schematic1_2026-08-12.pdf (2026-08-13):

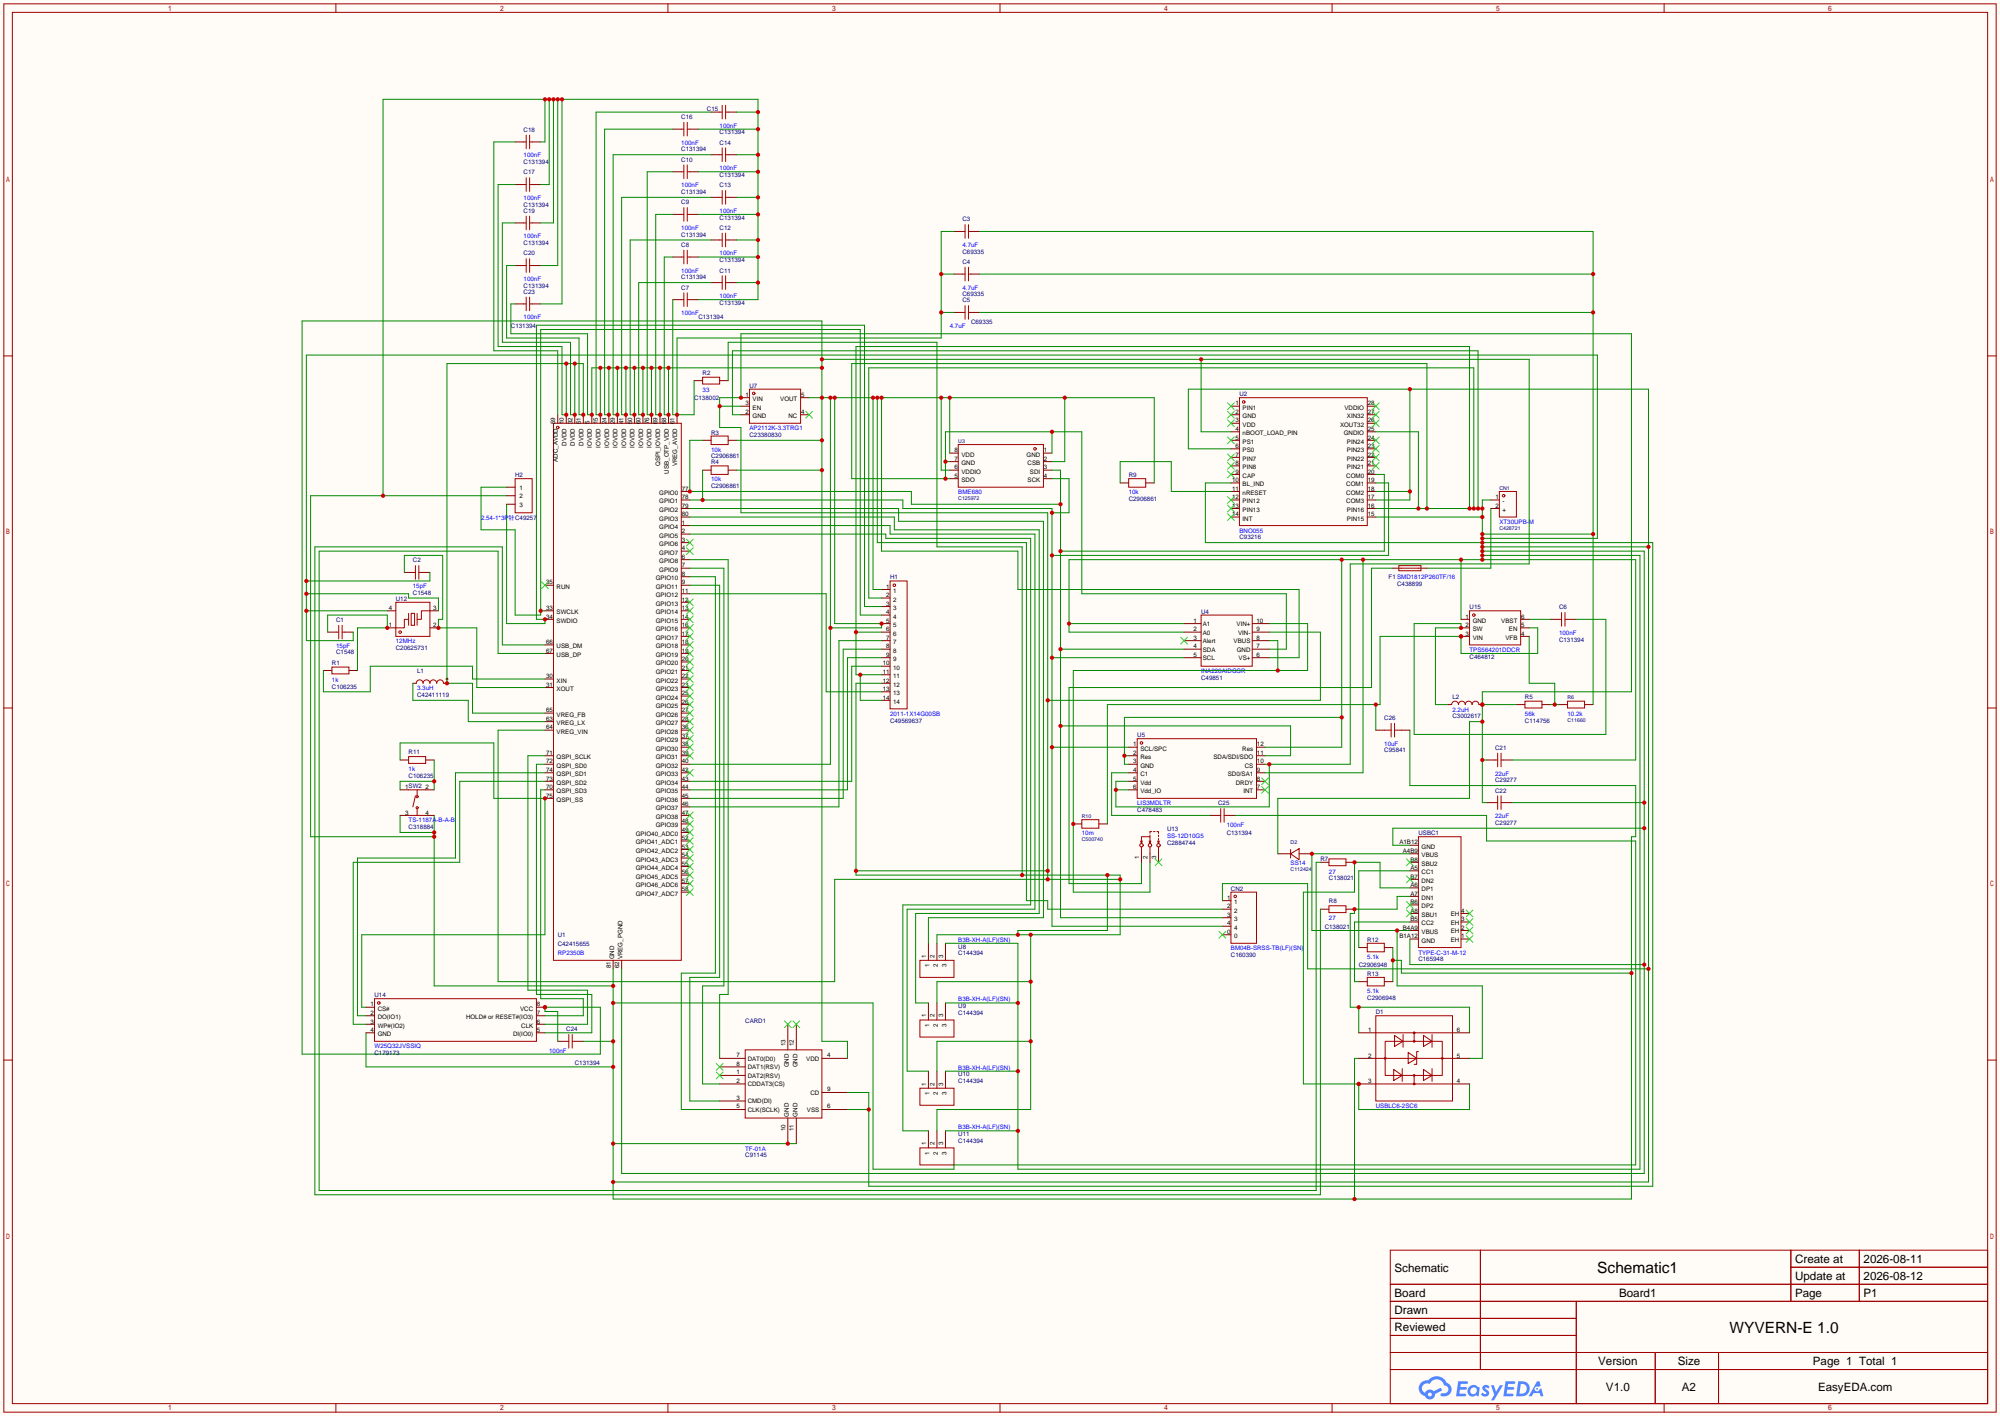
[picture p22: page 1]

Schematic | Schematic1 | Create at | 2026-08-11

Update at | 2026-08-12

Board | Board1 | Page | P1
Drawn | | WYVERN-E 1.0
Reviewed

Version | Size | Page 1 Total 1
V1.0 | A2 | EasyEDA.com

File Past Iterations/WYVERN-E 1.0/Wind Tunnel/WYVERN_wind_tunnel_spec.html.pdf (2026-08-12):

# XRIM-117 WYVERN PTD — Dedicated Aerodynamic Ground Test Facility

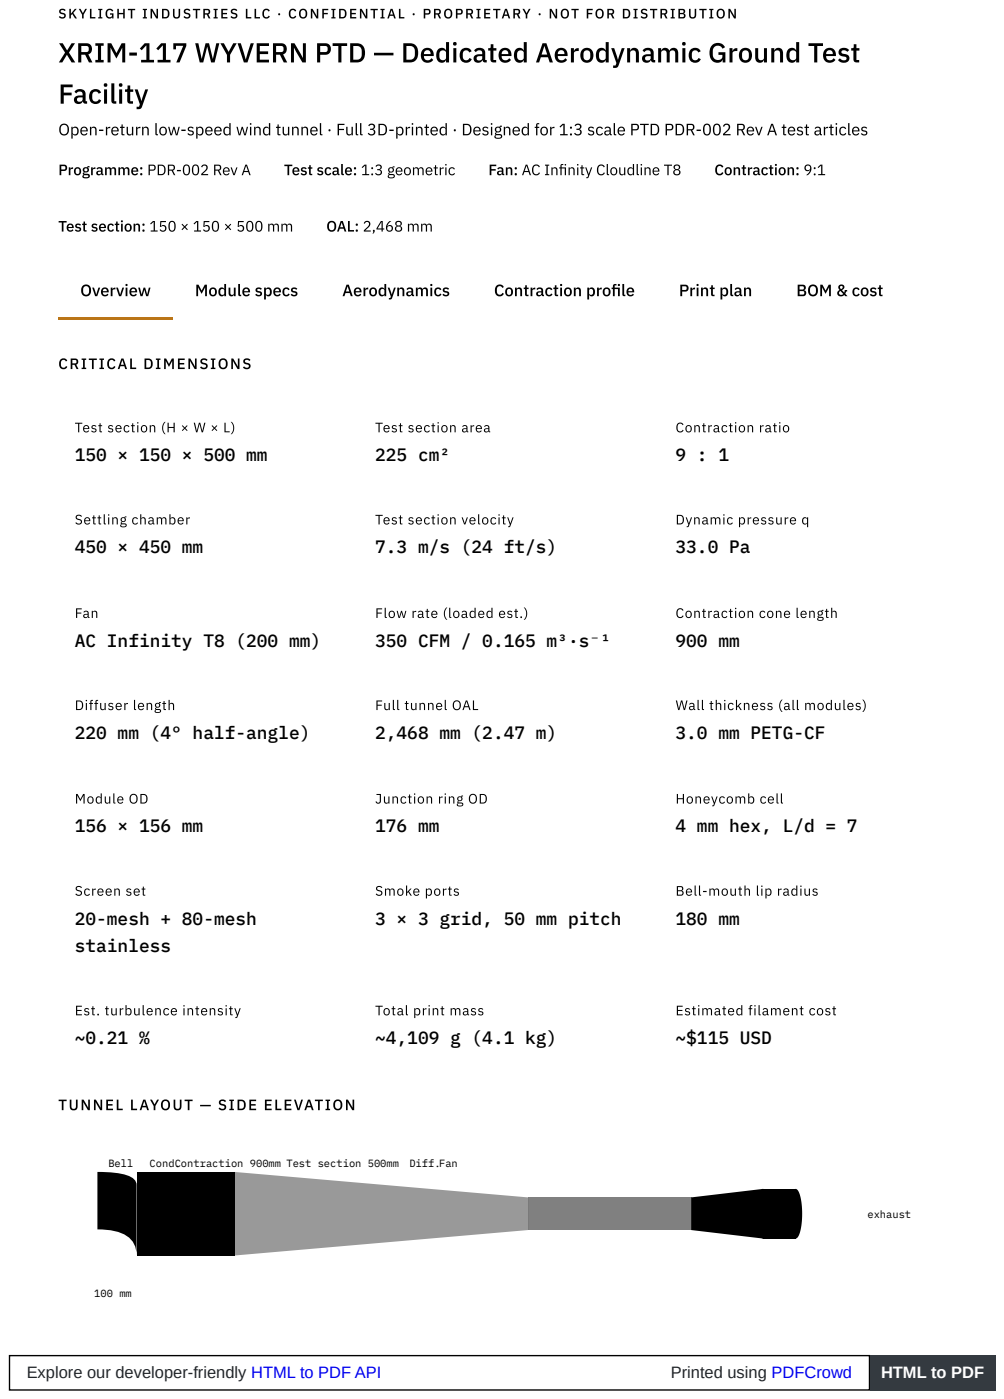
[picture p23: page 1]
Programme: PDR-002 Rev A; Test scale: 1:3 geometric; Fan: AC Infinity Cloudline T8; Contraction: 9:1; Test section: 150 × 150 × 500 mm; OAL: 2,468 mm; Overview; Module specs; Aerodynamics; Contraction profile; Print plan; BOM & cost; CRITICAL DIMENSIONS; Test section (H × W × L) 150 × 150 × 500 mm; Contraction ratio 9 : 1; Settling chamber 450 × 450 mm; Dynamic pressure q 33.0 Pa; Module OD 156 × 156 mm; Honeycomb cell 4 mm hex, L/d = 7; Screen set 20-mesh + 80-mesh stainless; exhaust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

SKYLIGHT INDUSTRIES LLC · CONFIDENTIAL · PROPRIETARY · NOT FOR DISTRIBUTION

Open-return low-speed wind tunnel · Full 3D-printed · Designed for 1:3 scale PTD PDR-002 Rev A test articles

Test section area
225 cm²

Test section velocity

Fan
AC Infinity T8 (200 mm)

Flow rate (loaded est.)
350 CFM / 0.165 m³·s⁻¹

Contraction cone length

Diffuser length
220 mm (4° half-angle)

Full tunnel OAL

Wall thickness (all modules)
3.0 mm PETG-CF

Junction ring OD

Smoke ports
3 × 3 grid, 50 mm pitch

Bell-mouth lip radius

Est. turbulence intensity

Total print mass

Estimated filament cost
~$115 USD

TUNNEL LAYOUT — SIDE ELEVATION

Bell Cond.Contraction 900mm Test section 500mm Diff.Fan

BLOCKAGE SUMMARY (1:3 SCALE MODEL, 150 × 150 MM TEST SECTION)

TEST ARTICLE | FRONTAL AREA | BLOCKAGE | STATUS
Nose cone on sting (body only) | 4.28 cm² | 1.9 % | No correction
Single fin panel — half-span wall mount | 5.44 cm² | 2.4 % | No correction
Ring 2 assembly + body stub | 6.97 cm² | 3.1 % | No correction
Ring 1 assembly + body stub | 15.17 cm² | 6.7 % | Maskell correction
Full rocket, 0° AoA (both rings) | 17.82 cm² | 7.9 % | Maskell correction
Full rocket, 45° roll | ~23.6 cm² | ~10.5 % | Visualization only

The 150 × 150 mm test section resolves the primary limitation of the source STEM tunnel (80 × 130 mm, 37%

blockage at 1:1). The full-rocket at 0° AoA now sits at 7.9% — within the Maskell-correctable range. At 1:3 scale,

body OD = 23.3 mm, Ring 1 fin span = 23.3 mm, OAL = 390 mm.

Explore our developer-friendly HTML to PDF API (https://pdfcrowd.com/api/html-to-pdf-api/?ref=pdf) | Printed using PDFCrowd (https://pdfcrowd.com/?ref=pdf) | HTML to PDF (https://pdfcrowd.com/html-to-pdf/?ref=pdf)

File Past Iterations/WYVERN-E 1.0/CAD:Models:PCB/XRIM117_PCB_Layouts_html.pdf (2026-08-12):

# XRIM-117 WYVERN 70mm PTD PDR-002 Rev A

PCB Layout Diagrams — CCM · ASAM-1 · ASAM-2 | Skylight Industries LLC | 62mm Circular, 2-Layer FR4, ENIG

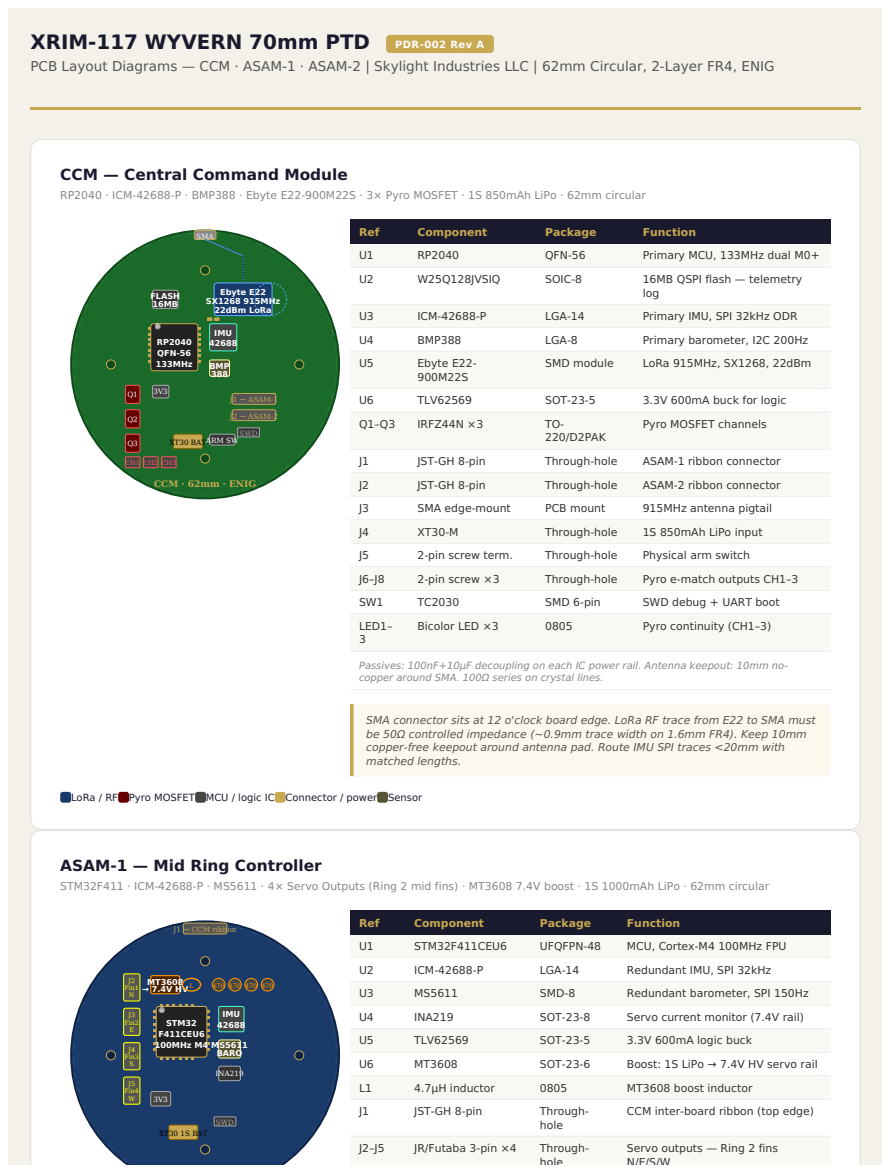
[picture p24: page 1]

CCM — Central Command Module
RP2040 · ICM-42688-P · BMP388 · Ebyte E22-900M22S · 3× Pyro MOSFET · 1S 850mAh LiPo · 62mm circular

Ref | Component | Package | Function
U1 | RP2040 | QFN-56 | Primary MCU, 133MHz dual M0+

Passives: 100nF+10μF decoupling on each IC power rail. Antenna keepout: 10mm no-
copper around SMA. 100Ω series on crystal lines.

SMA connector sits at 12 o'clock board edge. LoRa RF trace from E22 to SMA must
be 50Ω controlled impedance (~0.9mm trace width on 1.6mm FR4). Keep 10mm
copper-free keepout around antenna pad. Route IMU SPI traces <20mm with matched lengths.

LoRa / RF Pyro MOSFET MCU / logic IC Connector / power Sensor

ASAM-1 — Mid Ring Controller
STM32F411 · ICM-42688-P · MS5611 · 4× Servo Outputs (Ring 2 mid fins) · MT3608 7.4V boost · 1S 1000mAh LiPo · 62mm circular

U1 | STM32F411CEU6 | UFQFPN-48 | MCU, Cortex-M4 100MHz FPU

CCM inter-board ribbon (top edge)

Servo outputs — Ring 2 fins

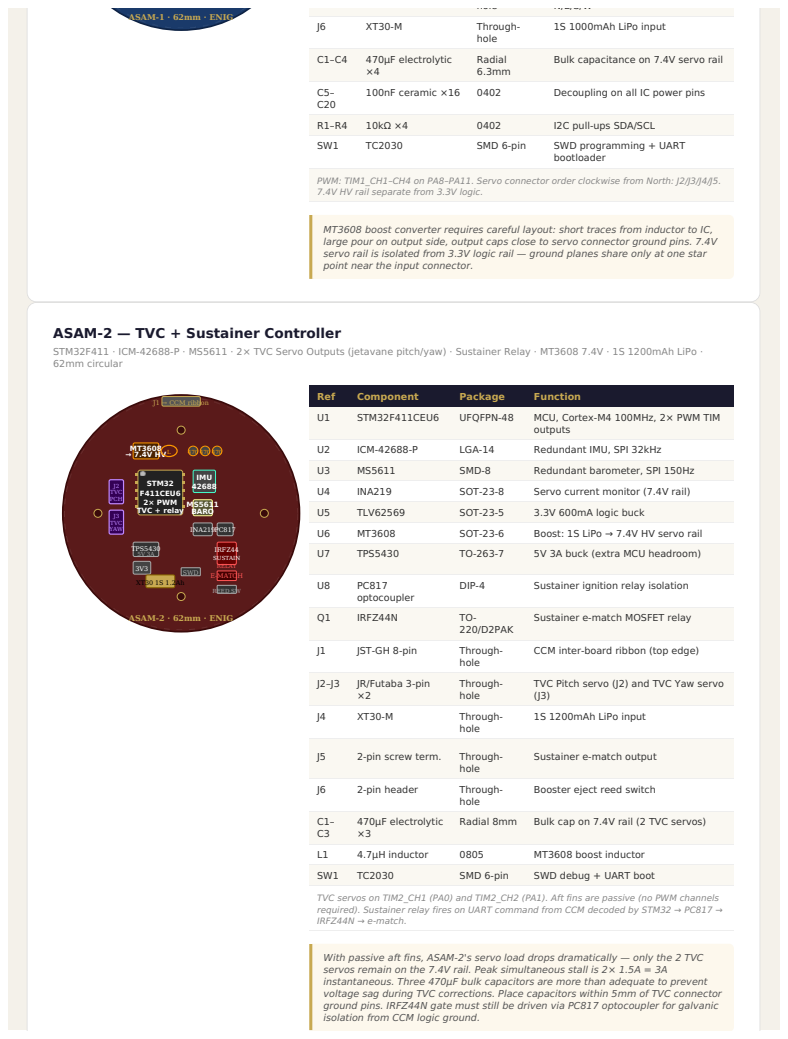
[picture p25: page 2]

Bulk capacitance on 7.4V servo rail

PWM: TIM1_CH1–CH4 on PA8–PA11. Servo connector order clockwise from North: J2/J3/J4/J5.
7.4V HV rail separate from 3.3V logic.

MT3608 boost converter requires careful layout: short traces from inductor to IC,
large pour on output side, output caps close to servo connector ground pins. 7.4V
servo rail is isolated from 3.3V logic rail — ground planes share only at one star
point near the input connector.

ASAM-2 — TVC + Sustainer Controller
STM32F411 · ICM-42688-P · MS5611 · 2× TVC Servo Outputs (jetavane pitch/yaw) · Sustainer Relay · MT3608 7.4V · 1S 1200mAh LiPo ·
62mm circular

Ref | Component | Package | Function
U1 | STM32F411CEU6 | UFQFPN-48 | MCU, Cortex-M4 100MHz, 2× PWM TIM outputs

Sustainer e-match MOSFET relay

CCM inter-board ribbon (top edge)

TVC Pitch servo (J2) and TVC Yaw servo
1S 1200mAh LiPo input

Booster eject reed switch

TVC servos on TIM2_CH1 (PA0) and TIM2_CH2 (PA1). Aft fins are passive (no PWM channels
required). Sustainer relay fires on UART command from CCM decoded by STM32 → PC817 →
IRFZ44N → e-match.

With passive aft fins, ASAM-2's servo load drops dramatically — only the 2 TVC
servos remain on the 7.4V rail. Peak simultaneous stall is 2× 1.5A = 3A
instantaneous. Three 470μF bulk capacitors are more than adequate to prevent
voltage sag during TVC corrections. Place capacitors within 5mm of TVC connector
ground pins. IRFZ44N gate must still be driven via PC817 optocoupler for galvanic
isolation from CCM logic ground.

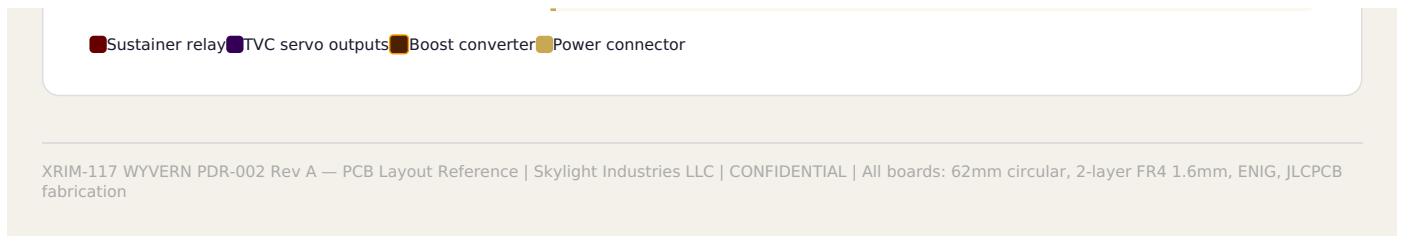
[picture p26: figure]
fabrication

Sustainer relay TVC servo outputs Boost converter Power connector

XRIM-117 WYVERN PDR-002 Rev A — PCB Layout Reference | Skylight Industries LLC | CONFIDENTIAL | All boards: 62mm circular, 2-layer FR4 1.6mm, ENIG, JLCPCB

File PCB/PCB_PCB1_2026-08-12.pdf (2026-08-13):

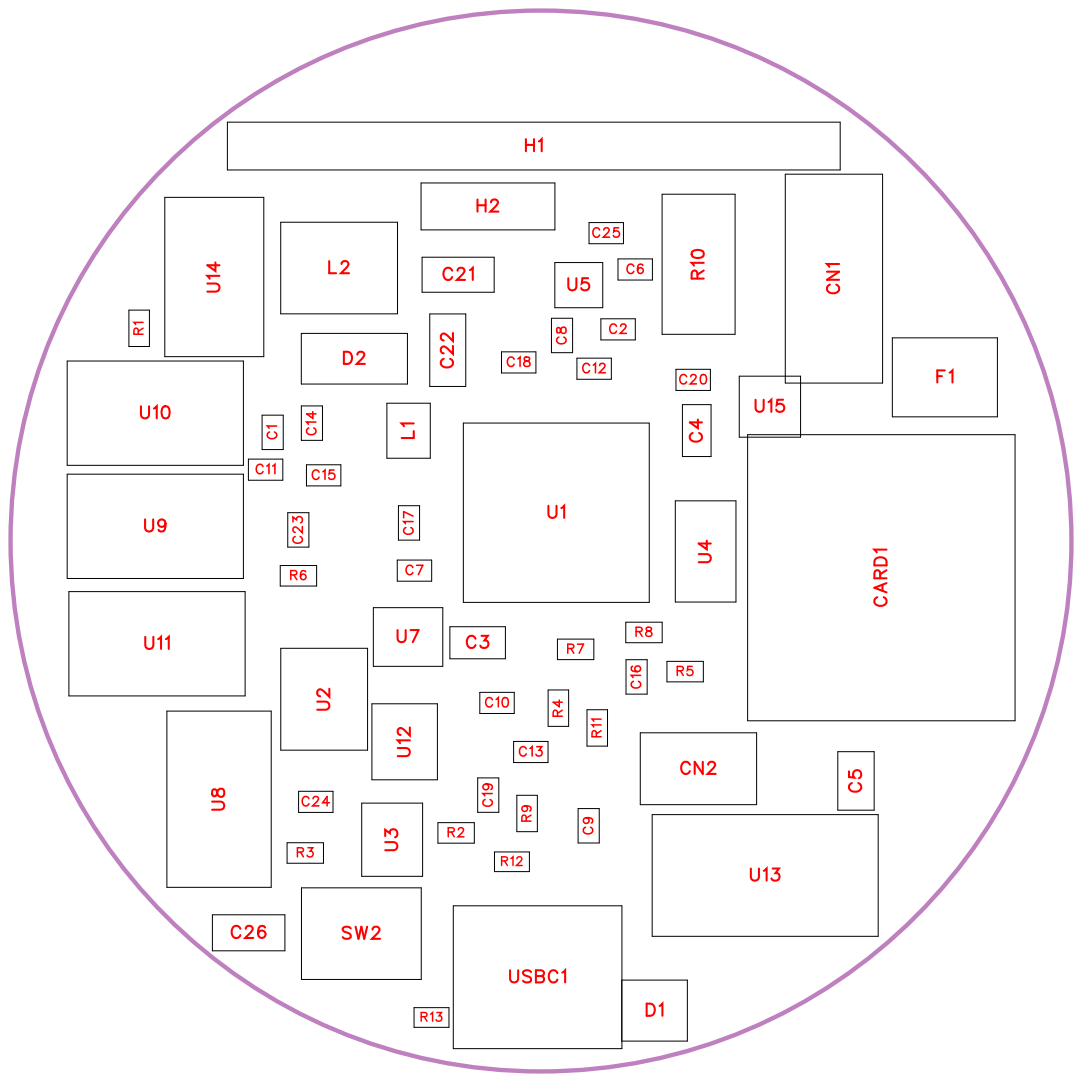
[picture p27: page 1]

No. | Quantity | Comment | Designator | Footprint | Value | Manufacturer Part | Manufacturer | Supplier Part | Supplier
1 | 2 | 15pF | C1,C2 | C0402 | 15pF | 0402CG150J 500NT | FH(风华) | C1548 | LCSC
2 | 3 | 4.7uF | C3,C4,C5 | C0603 | 4.7uF | CL10A475KA 8NQNC | SAMSUNG( 三星) | C69335 | LCSC
3 | 18 | 100nF | C6,C7,C8,C9,C10,C11,C12, C13,C14,C15,C16,C17,C18 ,C19,C20,C23,C24,C25 | C0402 | 100nF | CC0402KRX 7R9BB104 | YAGEO(国巨 ) | C131394 | LCSC
4 | 2 | 22uF | C21,C22 | C0805 | 22uF | CL21A226M PQNNNE | SAMSUNG( 三星) | C29277 | LCSC
5 | 1 | 10uF | C26 | C0805 | 10uF | CL21B106K OQNNNE | SAMSUNG( 三星) | C95841 | LCSC
6 | 1 | TF-01A | CARD1 | TF-SMD_TF-01A | | TF-01A | 韩国韩荣 | C91145 | LCSC
7 | 1 | XT30UPB-M | CN1 | CONN-TH_X T30UPB-M | | XT30UPB-M | AMASS(艾迈 斯) | C428721 | LCSC
8 | 1 | BM04B-SRS S-TB(LF)(SN ) | CN2 | CONN-SMD_ BM04B-SRS S-TB | | BM04B-SRS S-TB(LF)(SN ) | JST | C160390 | LCSC
9 | 1 | USBLC6-2S C6 | D1 | SOT-23-6_L2 .9-W1.6-P0.9 5-LS2.8-BL | | USBLC6-2S C6 | ST(意法半导 体) | C7519 | LCSC
10 | 1 | SS14 | D2 | SMA_L4.4-W 2.6-LS5.0-R D | | SS14 | 晶导微电子 | C112424 | LCSC
11 | 1 | SMD1812P2 60TF/16 | F1 | F1812 | | SMD1812P2 60TF/16 | PTTC(聚鼎) | C438899 | LCSC
12 | 1 | 2011-1X14G 00SB | H1 | HDR-TH_14 P-P2.54-V-M _4 | | 2011-1X14G 00SB | WingTAT(格 林柏) | C49569637 | LCSC
13 | 1 | 2.54-1*3P针 | H2 | HDR-TH_3P-P2.54-V-M-1 | | 2.54-1*3P针 | BOOMELE( 博穆精密) | C49257 | LCSC
14 | 1 | 3.3uH | L1 | IND-SMD_L2 .0-W1.6_AO TA-B201610 S3R3-101-T | 3.3uH | AOTA-B2016 10S3R3-101-T | ABRACON | C42411119 | LCSC
15 | 1 | 2.2uH | L2 | IND-SMD_L5 .7-W5.1 | 2.2uH | CKST0503-2. 2uH/M | CENKER(岑 科) | C3002617 | LCSC
16 | 2 | 1k | R1,R11 | R0402 | 1k | RC0402FR-0 71KL | YAGEO(国巨 ) | C106235 | LCSC
17 | 1 | 33 | R2 | R0402 | 33 | RC0402FR-0 733RL | YAGEO(国巨 ) | C138002 | LCSC
18 | 3 | 10k | R3,R4,R9 | R0402 | 10k | FRC0402F10 02TS | FOJAN(富捷) | C2906861 | LCSC
19 | 1 | 56k | R5 | R0402 | 56k | RC0402FR-0 756KL | YAGEO(国巨 ) | C114756 | LCSC
20 | 1 | 10.2k | R6 | R0402 | 10.2k | 0402WGF10 22TCE | UNI-ROYAL( 厚声) | C11660 | LCSC

21 | 2 | 27 | R7,R8 | R0402 | 27 | RC0402FR-0 727RL | YAGEO(国巨 ) | C138021 | LCSC
22 | 1 | 10m | R10 | R2512 | 10m | LR2512DS-3 W-10mR-1% | Milliohm(毫欧 ) | C500740 | LCSC
23 | 2 | 5.1k | R12,R13 | R0402 | 5.1k | FRC0402J51 2 TS | FOJAN(富捷 ) | C2906948 | LCSC
24 | 1 | TS-1187A-B-A-B | SW2 | SW-SMD_4P -L5.1-W5.1-P 3.70-LS6.5-T L_H1.5 | | TS-1187A-B-A-B | XKB Connect ion(中国星坤 ) | C318884 | LCSC
25 | 1 | RP2350B | U1 | QFN-80_L10. 0-W10.0-P0. 40-TL-EP3.4 | | RP2350B | Raspberry Pi(树莓派 ) | C42415655 | LCSC
26 | 1 | BNO055 | U2 | LGA-28_L5.2 -W3.8-P0.50-BL | | BNO055 | Bosch(博世 ) | C93216 | LCSC
27 | 1 | BME680 | U3 | LGA-8_L3.0-W3.0-P0.80-TR | | BME680 | Bosch(博世 ) | C125972 | LCSC
28 | 1 | INA226AIDG SR | U4 | MSOP-10_L3 .0-W3.0-P0.5 0-LS5.0-BL | | INA226AIDG SR | TI(德州仪器 ) | C49851 | LCSC
29 | 1 | LIS3MDLTR | U5 | LGA-12_L2.0 -W2.0-P0.50-BL | | LIS3MDLTR | ST(意法半导 体) | C478483 | LCSC
30 | 1 | AP2112K-3.3 TRG1 | U7 | SOT-23-5_L2 .9-W1.6-P0.9 5-LS2.8-BR | | AP2112K-3.3 TRG1 | TECH PUBLI C(台舟 ) | C23380830 | LCSC
31 | 4 | B3B-XH-A(L F)(SN) | U8,U9,U10,U11 | CONN-TH_3 P-P2.50_A25 01WV2-3P | | B3B-XH-A(L F)(SN) | JST | C144394 | LCSC
32 | 1 | 12MHz | U12 | CRYSTAL-S MD_4P-L3.2-W2.5-BL | 12MHz | ABM8-272-T 3 | ABRACON | C20625731 | LCSC
33 | 1 | SS-12D10G5 | U13 | SW-TH_SS-1 2D10L9 | | SS-12D10G5 | XKB Connect ion(中国星坤 ) | C2884744 | LCSC
34 | 1 | W25Q32JVS SIQ | U14 | SOIC-8_L5.3 -W5.3-P1.27-LS8.0-BL | | W25Q32JVS SIQ | Winbond( 华 ) 邦 | C179173 | LCSC
35 | 1 | TPS564201D DCR | U15 | SOT-23-6_L2 .9-W1.6-P0.9 5-LS2.8-BL | | TPS564201D DCR | TI(德州仪器 ) | C464812 | LCSC
36 | 1 | TYPE-C-31-M-12 | USBC1 | USB-C_SMD -TYPE-C-31-M-12_1 | | TYPE-C-31-M-12 | 韩国韩荣 | C165948 | LCSC

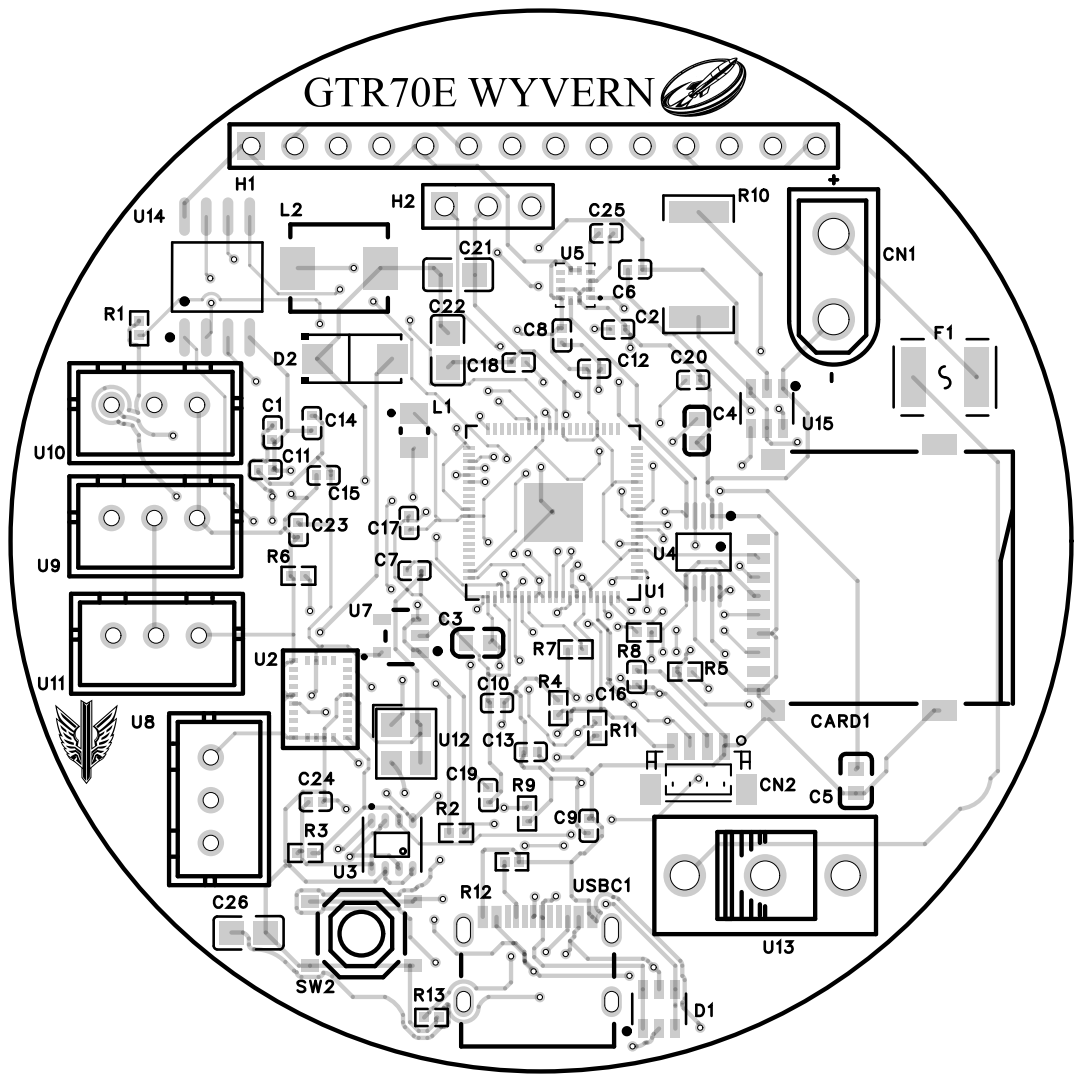
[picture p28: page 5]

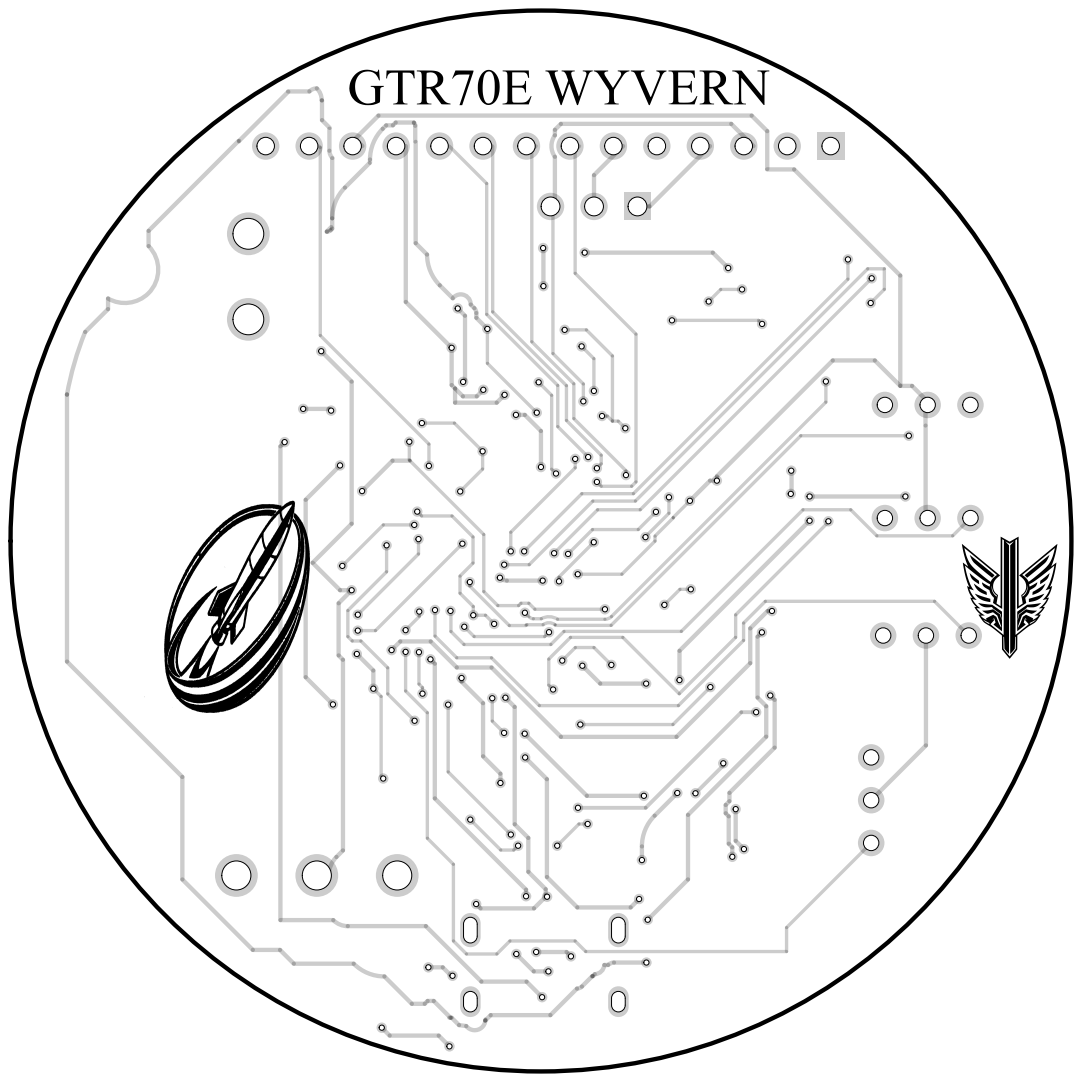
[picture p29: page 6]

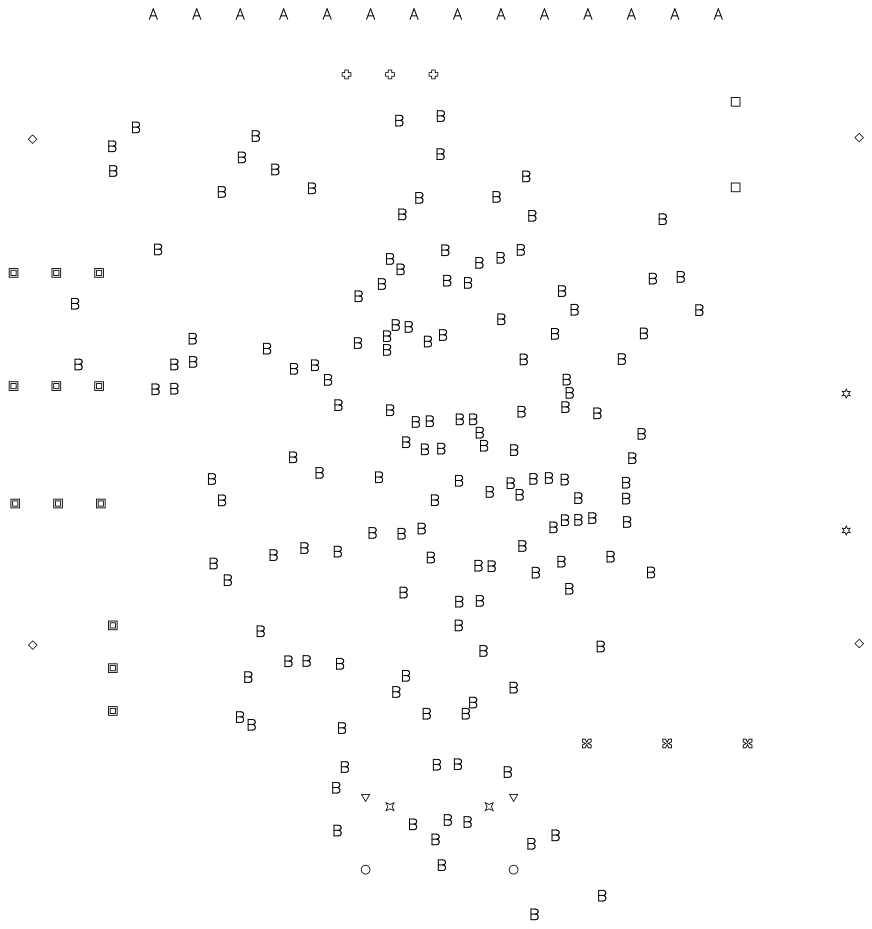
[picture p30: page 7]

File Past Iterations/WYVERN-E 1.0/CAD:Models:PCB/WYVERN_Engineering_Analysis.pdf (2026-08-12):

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

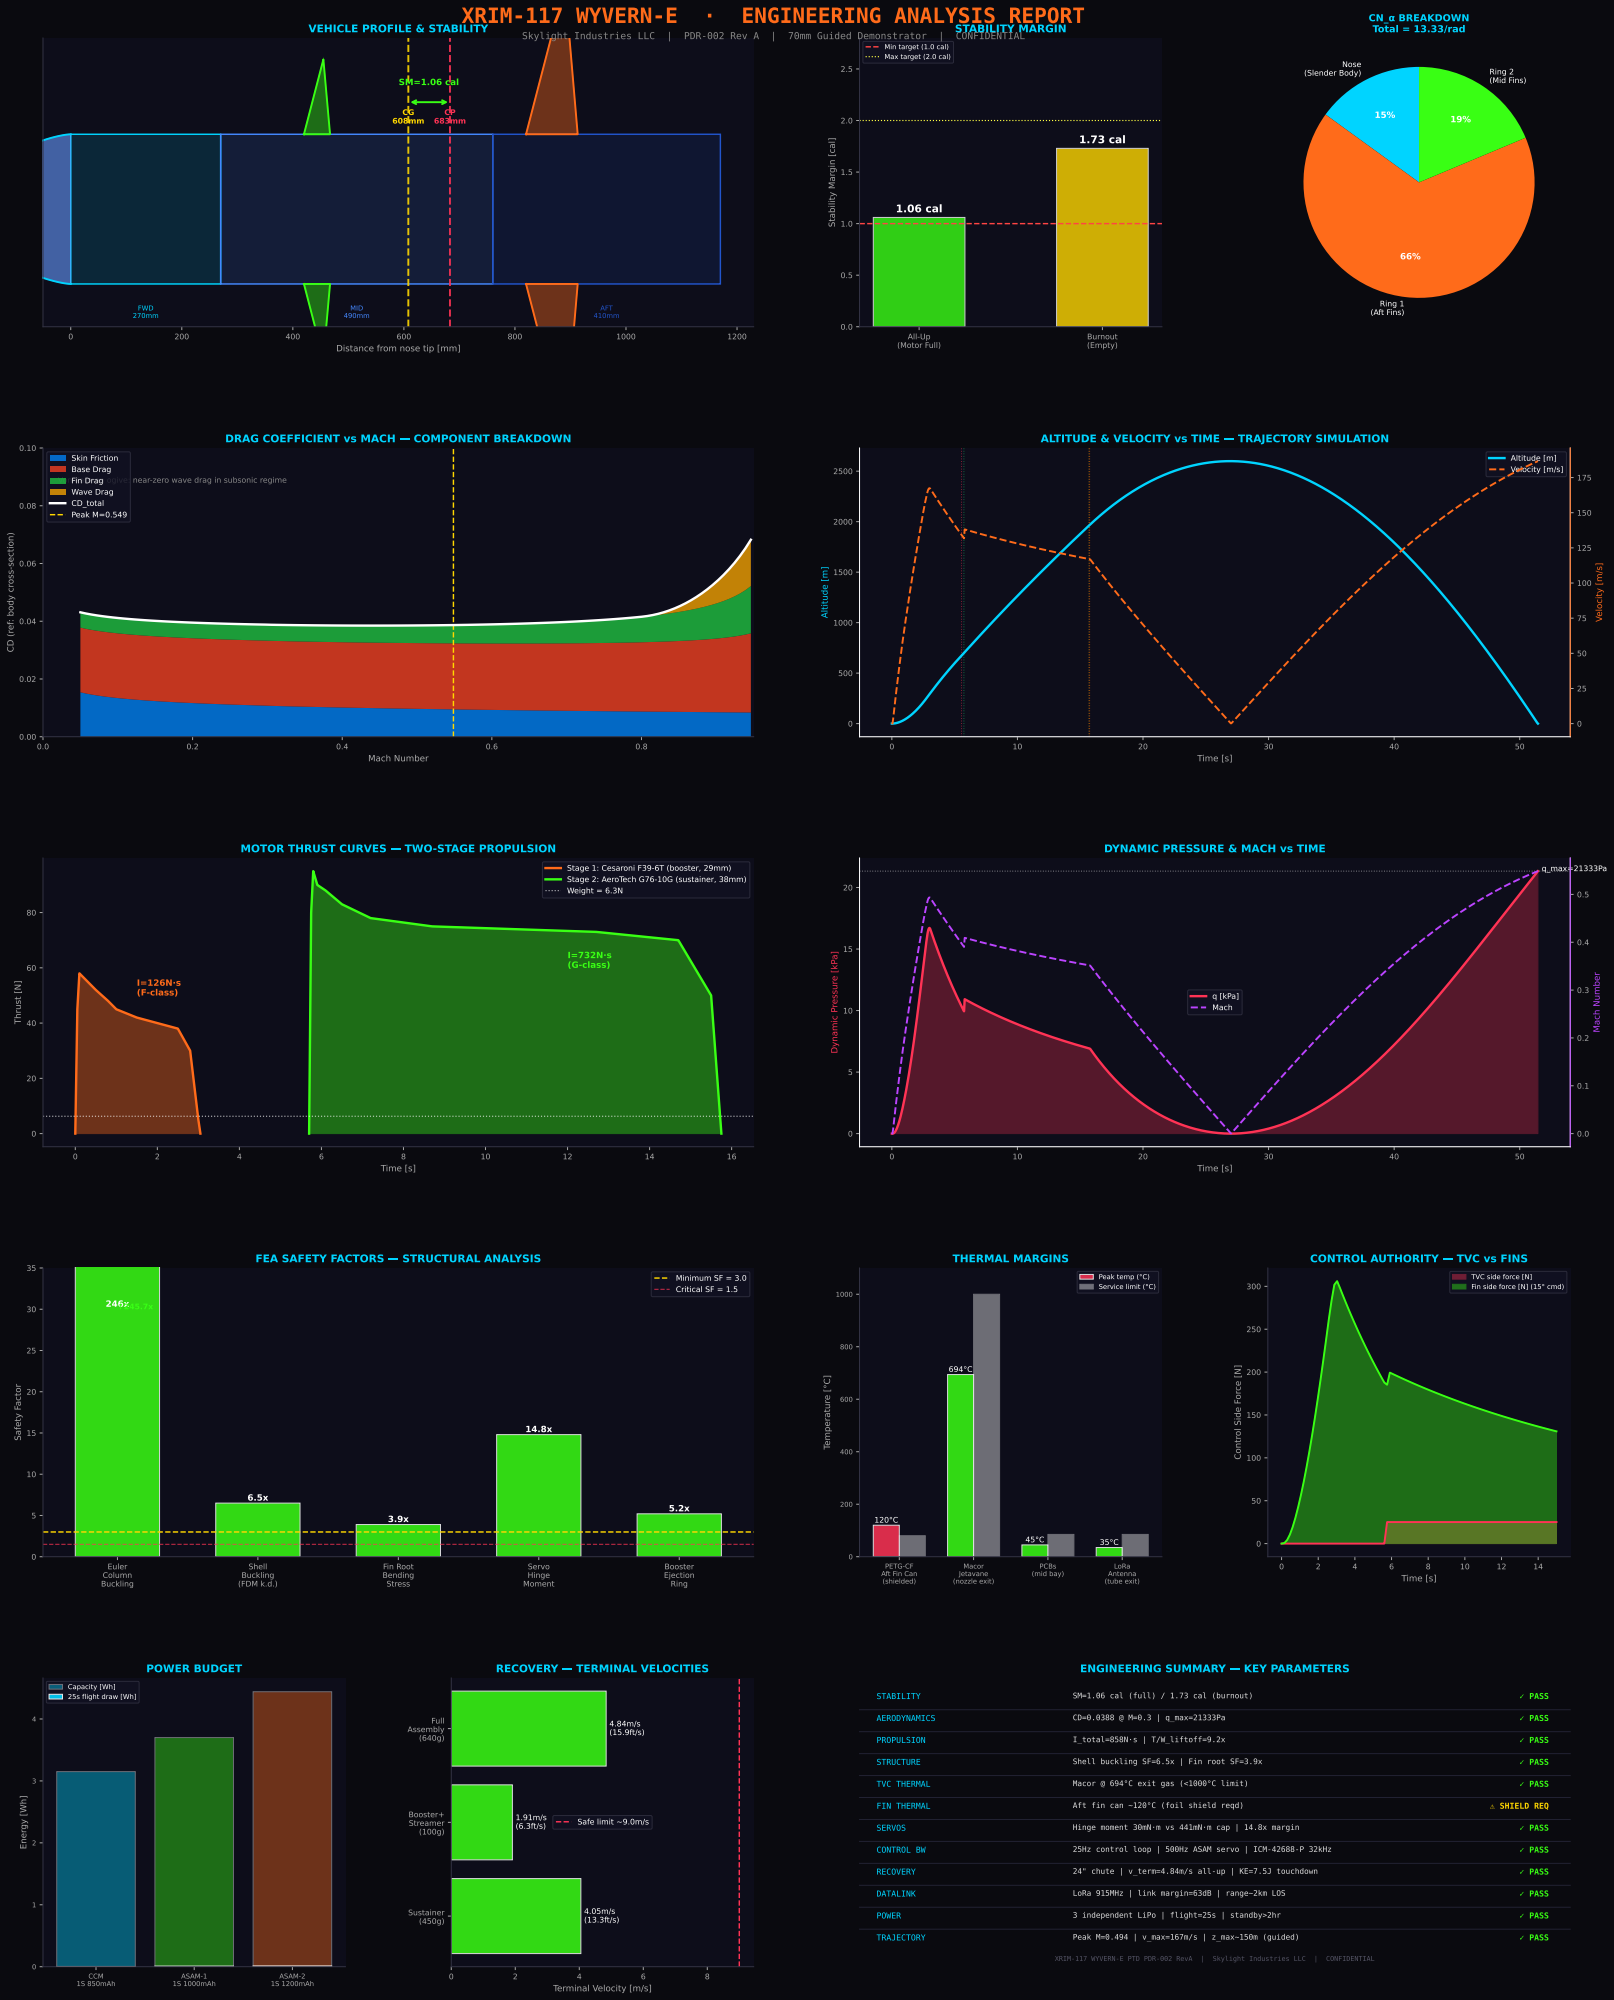
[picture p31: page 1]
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

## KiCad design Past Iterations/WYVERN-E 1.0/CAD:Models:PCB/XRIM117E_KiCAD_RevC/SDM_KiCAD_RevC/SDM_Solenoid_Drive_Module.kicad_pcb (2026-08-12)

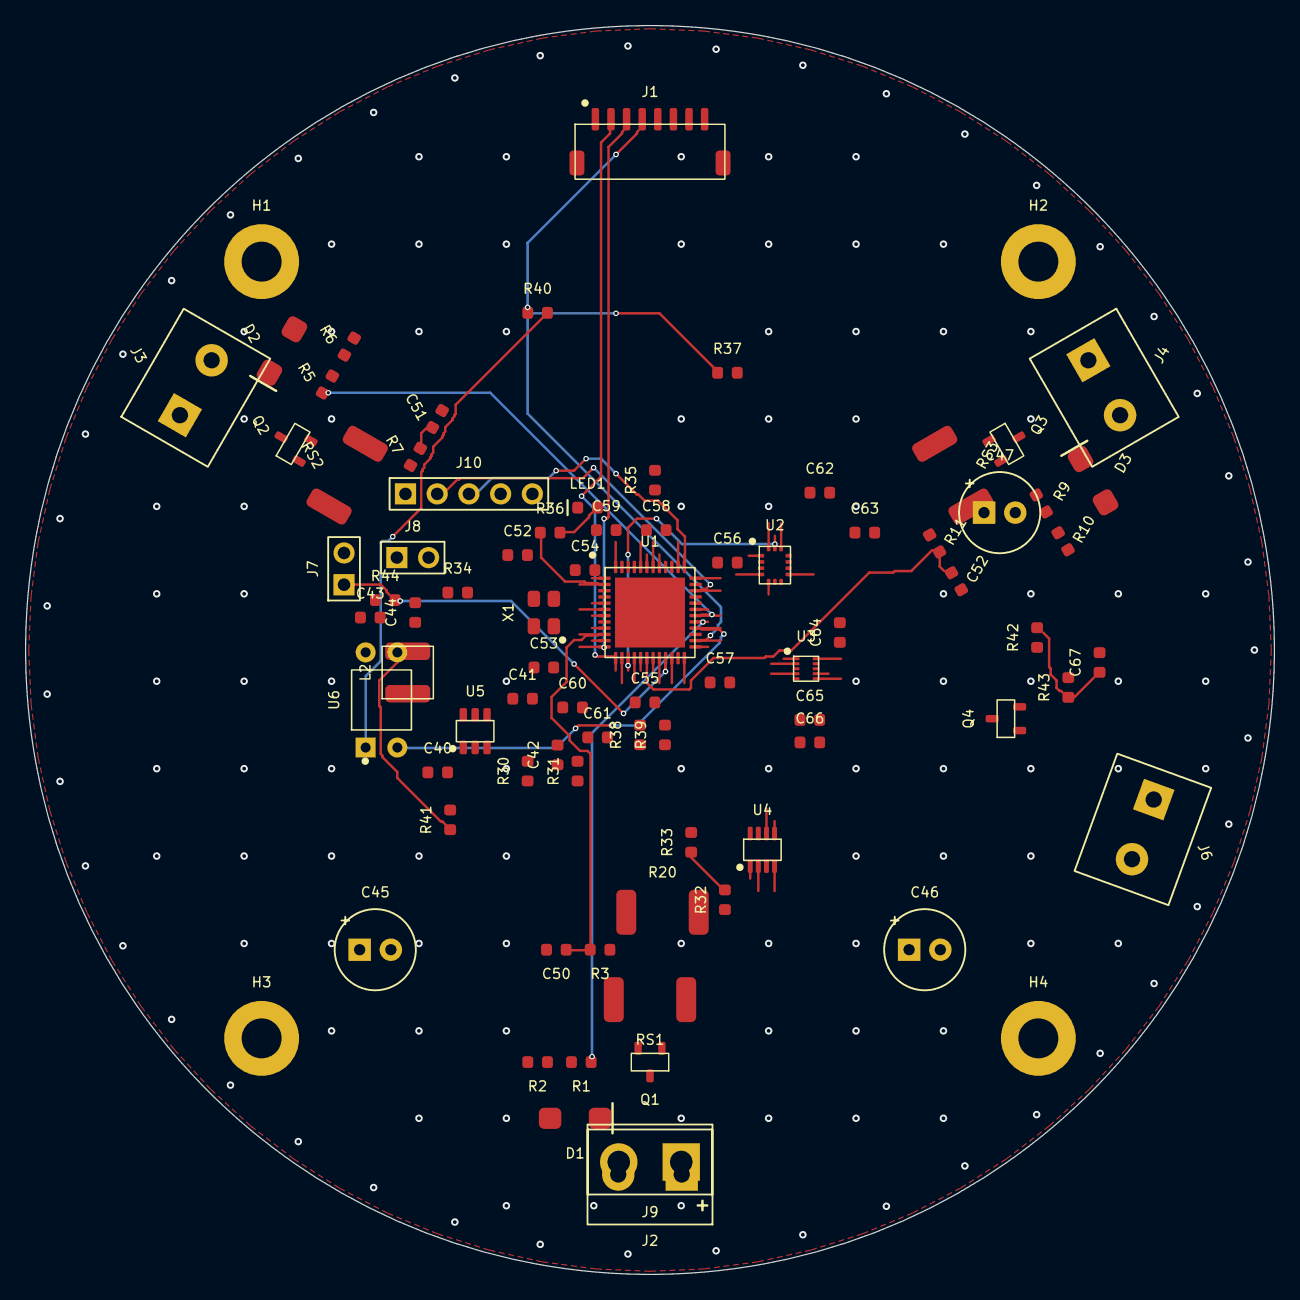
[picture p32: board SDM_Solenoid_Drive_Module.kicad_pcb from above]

Board: 2 copper layers, 100.0 x 100.0 mm, 84 parts (0 on the bottom side), 50 nets.

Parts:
C40, C50, C51, C52, C54, C56, C57, C58, C60, C62, C65, C66: 100nF; C_0603
C41, C42: 10uF 25V; C_0603
C43, C44: 22uF; C_0603
C45, C46, C47: 470uF; CP_Radial_D6.3mm_P2.50mm
C52#2, C53: 18pF; C_0603
C55: 4.7uF; C_0603
C59: 10uF; C_0603
C61: 1uF; C_0603
C63: 2.2uF; C_0603
C64, C67: 10nF; C_0603
D1, D2, D3: SS34; D_SMA
H1, H2, H3, H4: M3; MountingHole_M3
J1: to CCM; JST_GH_SM08B-GHS-TB
J2: SOL1; TerminalBlock_2P_5.08mm
J3: SOL2; TerminalBlock_2P_5.08mm
J4: SOL3; TerminalBlock_2P_5.08mm
J6: SUSTAIN; TerminalBlock_2P_5.08mm
J7: REED; PinHeader_1x02_P2.54mm
J8: BOOT0; PinHeader_1x02_P2.54mm
J9: XT30 2S; XT30_Male_Vertical
J10: SWD; PinHeader_1x05_P2.54mm
L2: 10uH; L_4x4mm
LED1: STAT; LED_0603
Q1, Q2, Q3, Q4: AO3400A; SOT-23
R1, R5, R9: 100R; R_0603
R2, R6, R10, R32, R37, R41, R42: 100k; R_0603
R3, R7, R11, R36: 1k; R_0603
R20: 10m 2512; R_2512_Shunt
R30: 45.3k; R_0603
R31, R34, R35, R44: 10k; R_0603
R33, R43: 27k; R_0603
R38, R39: 4.7k; R_0603
R40: 330R; R_0603
RS1, RS2, RS3: 20m 2512; R_2512_Shunt
U1: STM32F411CEU6; UFQFPN-48_7x7mm_P0.5mm
U2: ICM-42688-P; ICM-42688-P_LGA-14_2.5x3mm
U3: BMP388; BMP388_LGA-10_2x2mm
U4: INA219; SOT-23-8
U5: TPS54202; SOT-23-6
U6: PC817; PC817_DIP-4
X1: 8MHz; Crystal_3225_4Pin

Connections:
+3V3: C43.1, C44.1, C56.1, C57.1, C58.1, C59.1, C60.1, C61.1, C62.1, C63.1, C64.1, C65.1, C66.1, J8.2, J10.1, L2.2, R30.1, R38.1, R39.1, R44.1, U1.1, U1.9, U1.24, U1.36, U1.48, U2.5, U2.8, U3.1, U3.6, U3.10, U4.4
ARM_IN: J1.4, R37.1, R40.1, U1.26
ARM_IN_R: R40.2, U6.1
BMP_INT: U1.41, U3.7
BOOT0: J8.1, R34.1, U1.44
BUCK_BOOT: C40.1, U5.6
BUCK_FB: R30.2, R31.1, U5.4
BUCK_SW: C40.2, L2.1, U5.2
GND: C41.2, C42.2, C43.2, C44.2, C45.2, C46.2, C47.2, C50.2, C51.2, C52.2, C52#2.2, C53.2, C54.2, C55.2, C56.2, C57.2, C58.2, C59.2, C60.2, C61.2, C62.2, C63.2, C64.2, C65.2, C66.2, C67.2, J1.1, J1.7, J1.8, J1.MP1, J1.MP2, J7.2, J9.2, J10.5, LED1.1, Q4.2, R2.2, R6.2, R10.2, R31.2, R33.2, R34.2, R35.2, R37.2, R41.2, R43.2, RS1.2, RS2.2, RS3.2, U1.8, U1.23, U1.35, U1.47, U1.49, U2.6, U2.7, U2.9, U3.3, U3.5, U3.8, U3.9, U4.3, U4.7, U4.8, U5.1, X1.2, X1.4
I2C1_SCL: R39.2, U1.42, U3.2, U4.5
I2C1_SDA: R38.2, U1.43, U3.4, U4.6
IMU_CS: U1.25, U2.12
IMU_INT1: U1.38, U2.4
LED_R: LED1.2, R36.2
LED_STATUS: R36.1, U1.2
NRST: C54.1, J10.4, U1.7
PB2_STRAP: R35.1, U1.20
REED: J7.1, R44.2, U1.21
SOL1_D: D1.1, J2.2, Q1.3
SOL1_G: Q1.1, R1.2, R2.1
SOL1_PWM: R1.1, U1.29
SOL1_SH: Q1.2, R3.1, RS1.1
SOL1_SNS: C50.1, R3.2, U1.10
SOL2_D: D2.1, J3.2, Q2.3
SOL2_G: Q2.1, R5.2, R6.1
SOL2_PWM: R5.1, U1.30
SOL2_SH: Q2.2, R7.1, RS2.1
SOL2_SNS: C51.1, R7.2, U1.11
SOL3_D: D3.1, J4.2, Q3.3
SOL3_G: Q3.1, R9.2, R10.1
SOL3_PWM: R9.1, U1.31
SOL3_SH: Q3.2, R11.1, RS3.1
SOL3_SNS: C52.1, R11.2, U1.18
SPI1_MISO: U1.16, U2.1
SPI1_MOSI: U1.17, U2.14
SPI1_SCK: U1.15, U2.13
SUS_CONT: C67.1, R42.2, R43.1, U1.14
SUS_D: J6.2, Q4.3, R42.1
SUS_FIRE: U1.28, U6.2
SUS_GATE: Q4.1, R41.1, U6.3
SWCLK: J10.3, U1.37
SWDIO: J10.2, U1.34
UART_RX: J1.2, U1.13
UART_TX: J1.3, U1.12
VBAT2S: C41.1, C42.1, J6.1, J9.1, R20.1, R32.1, U4.1, U5.3, U6.4
VBAT_SENSE: R32.2, R33.1, U1.19
VCAP: C55.1, U1.22
V_SOL: C45.1, C46.1, C47.1, D1.2, D2.2, D3.2, J2.1, J3.1, J4.1, R20.2, U4.2
XIN: C52#2.1, U1.5, X1.1
XOUT: C53.1, U1.6, X1.3

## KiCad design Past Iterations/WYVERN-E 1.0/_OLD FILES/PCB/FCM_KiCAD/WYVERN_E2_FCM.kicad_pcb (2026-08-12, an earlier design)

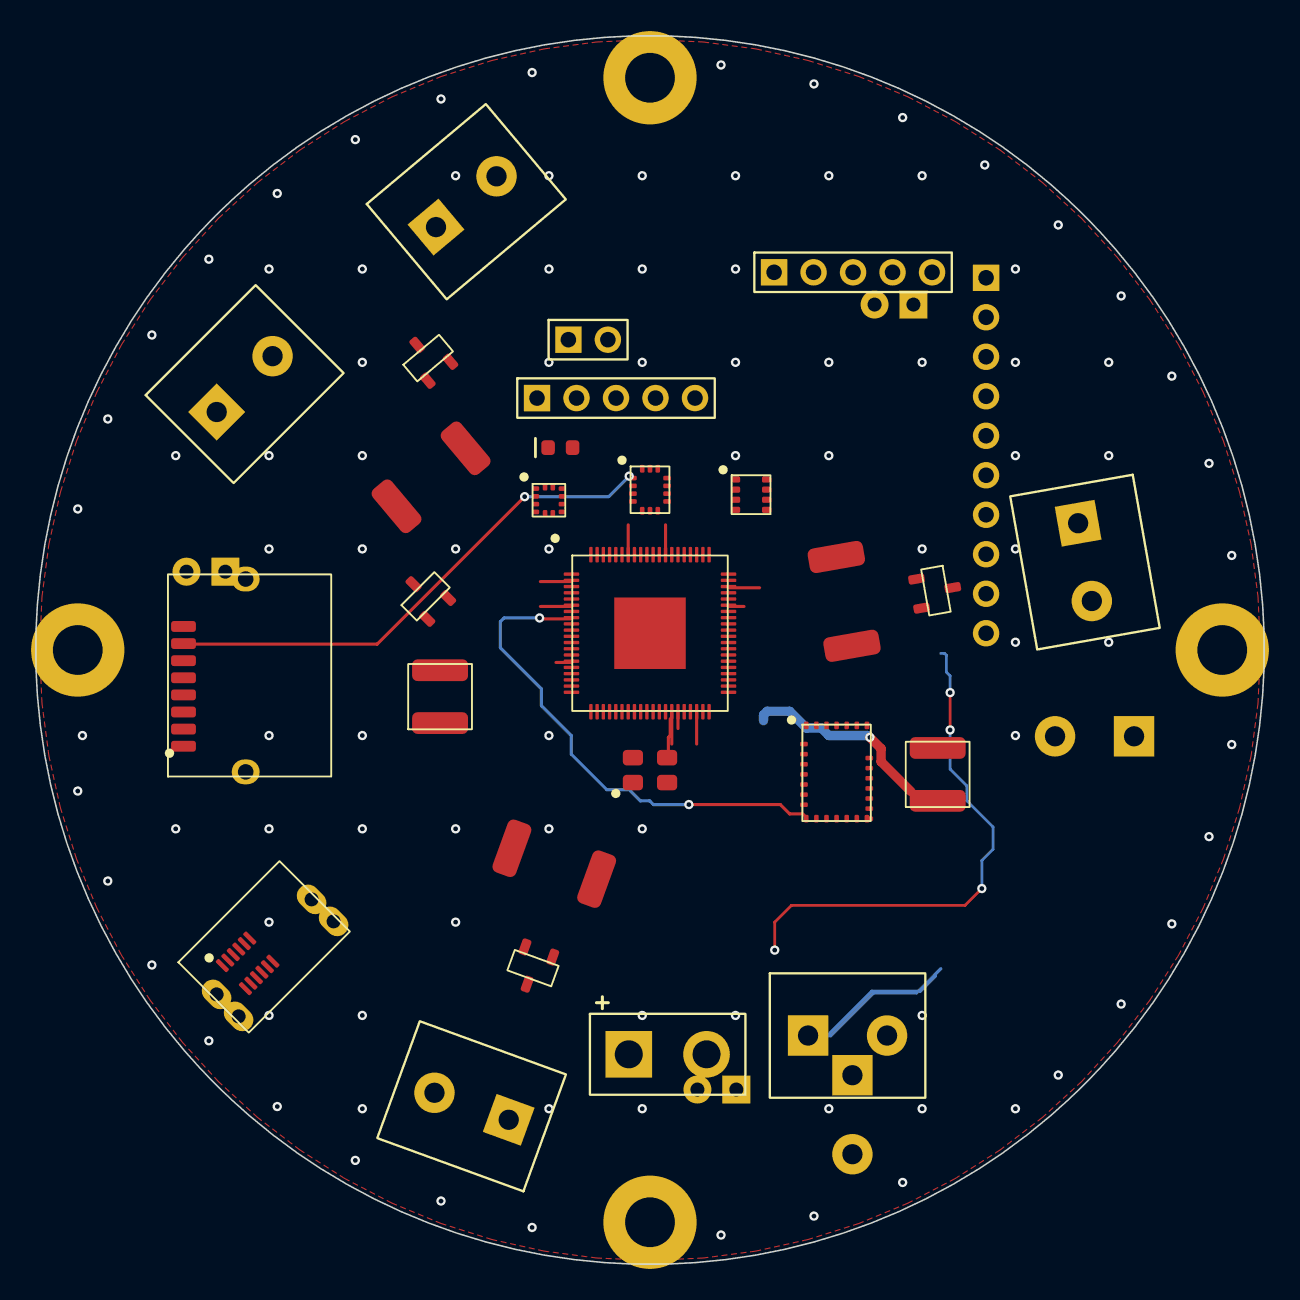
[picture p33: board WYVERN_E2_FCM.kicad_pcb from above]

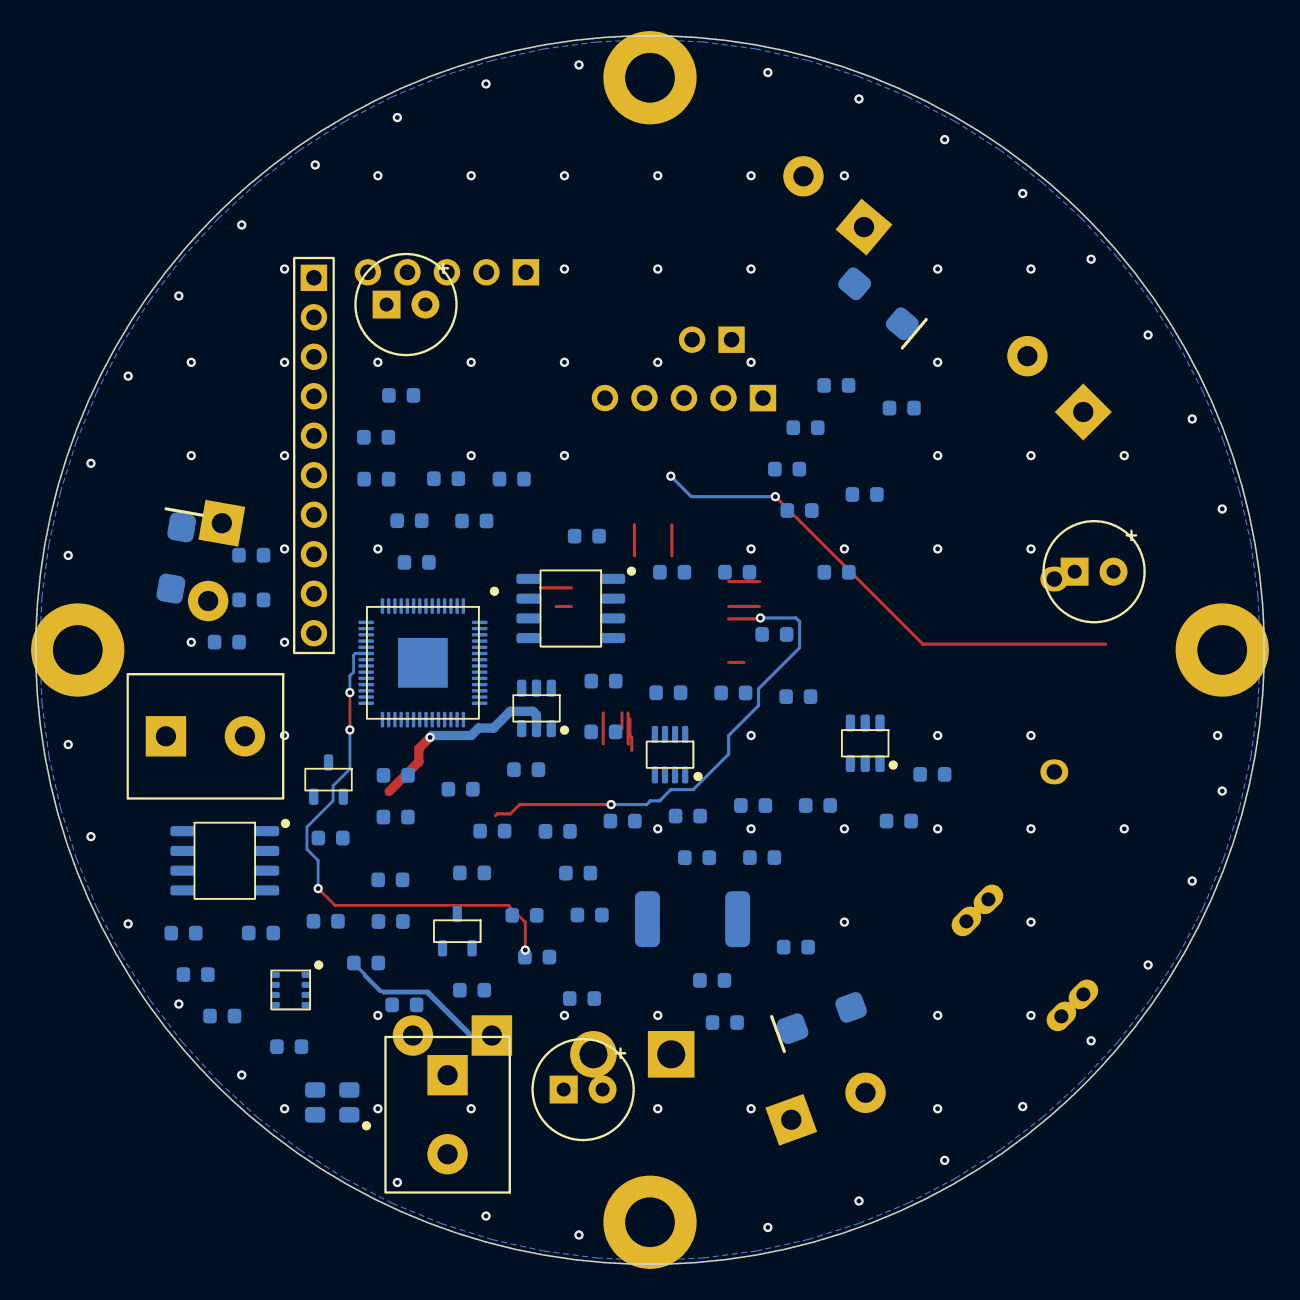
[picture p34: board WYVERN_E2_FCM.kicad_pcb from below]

Board: 4 copper layers, 79.0 x 79.0 mm, 113 parts (82 on the bottom side), 81 nets.

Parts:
C1, C2, C71, C72: 18pF; C_0603
C3, C10, C11, C12, C13, C14, C15, C16, C17, C20, C40, C41, C42, C70, C74, C75, C76, C77, C78, C79, C80: 100nF; C_0603
C30, C31, C32: 470uF; CP_Radial_D6.3mm_P2.50mm
C50, C73: 1uF; C_0603
D1, D2, D3: SS34; D_SMA
H1, H2, H3, H4: M3; MountingHole_M3
J1: SWD; PinHeader_1x05_P2.54mm
J2: USB-C; USB-C_Receptacle_2.0
J3: microSD; microSD_Push_Molex
J4: BNO055; PinHeader_1x10_P2.54mm
J5: VIBE; TerminalBlock_2P_5.08mm
J6: 12V NiCd; XT30_Male_Vertical
J7: SOL1; TerminalBlock_2P_5.08mm
J8: SOL2; TerminalBlock_2P_5.08mm
J9: SOL3; TerminalBlock_2P_5.08mm
J11: 2ND IGN; TerminalBlock_2P_5.08mm
J12: REED; PinHeader_1x02_P2.54mm
J14: DROGUE PYRO; TerminalBlock_2P_5.08mm
J15: MAIN PYRO; TerminalBlock_2P_5.08mm
J16: DEPLOY SWD; PinHeader_1x05_P2.54mm
L1, L2: 10uH; L_4x4mm
LED1: STAT; LED_0603
Q1, Q2, Q3, Q4, Q5, Q6: AO3400A; SOT-23
R1, R9, R11, R44, R60: 10k; R_0603
R2, R3: 5.1k; R_0603
R4, R5, R61, R62: 4.7k; R_0603
R6: 1M; R_0603
R7: 10m; R_2512_Shunt
R8: 45.3k; R_0603
R10: 73.2k; R_0603
R12, R21, R25, R29, R40, R41, R45, R46, R47, R49: 100k; R_0603
R13, R42, R48, R50: 18k; R_0603
R20, R24, R28: 100R; R_0603
R22, R26, R30, R43: 1k; R_0603
RS1, RS2, RS3: 20m; R_2512_Shunt
U1: RP2350B; QFN-80-1EP_10x10mm_P0.4mm
U2, U11: W25Q32JV; SOIC-8_3.9x4.9mm_P1.27mm
U4: ICM-42688-P; ICM-42688-P_LGA-14_2.5x3mm
U5, U12: BMP280; BME280_LGA-8_2.5x2.5mm
U6: LIS3MDL; LIS3MDL_LGA-12_2x2mm
U7: INA219; SOT-23-8
U8: TPS54202_3V3; SOT-23-6
U9: TPS54202_5V; SOT-23-6
U10: RP2040; QFN-56-1EP_7x7mm_P0.4mm
U13: BNO055; BNO055_LGA-28_3.8x5.2mm
X1, X2: 12MHz; Crystal_3225_4Pin

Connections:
+1V1: C50.1, C73.1, U1.18, U1.20, U1.60, U10.23, U10.45, U10.50
+3V3: C3.1, C10.1, C11.1, C12.1, C13.1, C14.1, C15.1, C16.1, C17.1, C20.1, C70.1, C74.1, C75.1, C76.1, C77.1, C78.1, C79.1, C80.1, J1.1, J3.4, J4.1, J4.2, J16.1, L1.2, R1.1, R4.1, R5.1, R8.1, R44.1, R60.1, R61.1, R62.1, U1.1, U1.11, U1.19, U1.21, U1.31, U1.39, U1.40, U1.41, U1.51, U1.61, U1.69, U1.70, U1.71, U1.78, U1.79, U1.80, U2.8, U4.5, U4.8, U5.1, U5.4, U5.6, U6.1, U6.5, U6.12, U7.4, U10.1, U10.10, U10.22, U10.33, U10.42, U10.43, U10.44, U10.48, U10.49, U11.8, U12.1, U12.4, U12.6, U13.1, U13.5, U13.13, U13.19, U13.26
+5V: L2.2, R10.1
BK3_FB: R8.2, R9.1, U8.4
BK3_SW: L1.1, U8.2
BK5_FB: R10.2, R11.1, U9.4
BK5_SW: L2.1, U9.2
BNO_INT: J4.7, U1.56
BNO_O_INT: U1.8, U13.8
CC1: J2.3, R2.1
CC2: J2.4, R3.1
DEP_ARM: U1.6, U10.7
DEP_I2C_SCL: R62.2, U10.12, U12.7
DEP_I2C_SDA: R61.2, U10.11, U12.3
DEP_QSPI_SCLK: U10.52, U11.6
DEP_QSPI_SD0: U10.53, U11.5
DEP_QSPI_SD1: U10.55, U11.2
DEP_QSPI_SD2: U10.54, U11.3
DEP_QSPI_SD3: U10.51, U11.7
DEP_QSPI_SS: U10.56, U11.1
DEP_RUN: J16.4, R60.2, U10.26
DEP_STATUS: U1.7, U10.9
DEP_SWCLK: J16.3, U10.24
DEP_SWD: J16.2, U10.25
DEP_UART_RX: U1.5, U10.3
DEP_UART_TX: U1.4, U10.2
DEP_XIN: C71.1, U10.20, X2.1
DEP_XOUT: C72.1, U10.21, X2.3
GND: C1.2, C2.2, C3.2, C10.2, C11.2, C12.2, C13.2, C14.2, C15.2, C16.2, C17.2, C20.2, C30.2, C31.2, C32.2, C40.2, C41.2, C42.2, C50.2, C70.2, C71.2, C72.2, C73.2, C74.2, C75.2, C76.2, C77.2, C78.2, C79.2, C80.2, J1.5, J2.2, J3.6, J4.3, J4.8, J4.9, J4.10, J5.2, J6.2, J12.2, J16.5, LED1.1, Q4.2, Q5.2, Q6.2, R2.2, R3.2, R6.2, R9.2, R11.2, R13.2, R21.2, R25.2, R29.2, R40.2, R42.2, R45.2, R46.2, R48.2, R50.2, RS1.2, RS2.2, RS3.2, U1.81, U2.4, U4.6, U4.7, U4.9, U5.2, U5.5, U5.8, U6.2, U6.3, U6.4, U6.8, U6.9, U6.10, U6.11, U7.3, U7.7, U7.8, U8.1, U9.1, U10.19, U10.57, U11.4, U12.2, U12.5, U12.8, U13.2, U13.3, U13.4, U13.9, U13.10, U13.11, U13.12, U13.14, U13.15, U13.16, U13.17, U13.18, U13.20, U13.21, U13.22, U13.23, U13.24, U13.25, U13.27, U13.28, X1.2, X1.4, X2.2, X2.4
I2C0_SCL: J4.5, R5.2, U1.47, U5.7, U6.6, U7.5, U13.6
I2C0_SDA: J4.4, R4.2, U1.46, U5.3, U6.7, U7.6, U13.7
IMU_CS: U1.17, U4.12
IMU_INT1: U1.55, U4.4
LED_R: LED1.2, R43.2
PYRO_DROG_CONT: R47.2, R48.1, U10.39
PYRO_DROG_D: J14.2, Q5.3, R47.1
PYRO_DROG_GATE: Q5.1, R45.1, U10.5
PYRO_IGN_CONT: R41.2, R42.1, U10.38
PYRO_IGN_D: J11.2, Q4.3, R41.1
PYRO_IGN_GATE: Q4.1, R40.1, U10.4
PYRO_MAIN_CONT: R49.2, R50.1, U10.40
PYRO_MAIN_D: J15.2, Q6.3, R49.1
PYRO_MAIN_GATE: Q6.1, R46.1, U10.6
QSPI_SCLK: U1.73, U2.6
QSPI_SD0: U1.74, U2.5
QSPI_SD1: U1.76, U2.2
QSPI_SD2: U1.75, U2.3
QSPI_SD3: U1.72, U2.7
QSPI_SS: U1.77, U2.1
REED: J12.1, R44.2, U1.57
RUN: J1.4, J4.6, R1.2, U1.32
SD_CS: J3.2, U1.23
SOL1_D: D1.1, J7.2, Q1.3
SOL1_G: Q1.1, R20.2, R21.1
SOL1_PWM: R20.1, U1.48
SOL1_SH: Q1.2, R22.1, RS1.1
SOL1_SNS: C40.1, R22.2, U1.59
SOL2_D: D2.1, J8.2, Q2.3
SOL2_G: Q2.1, R24.2, R25.1
SOL2_PWM: R24.1, U1.49
SOL2_SH: Q2.2, R26.1, RS2.1
SOL2_SNS: C41.1, R26.2, U1.62
SOL3_D: D3.1, J9.2, Q3.3
SOL3_G: Q3.1, R28.2, R29.1
SOL3_PWM: R28.1, U1.50
SOL3_SH: Q3.2, R30.1, RS3.1
SOL3_SNS: C42.1, R30.2, U1.63
SPI1_MISO: J3.7, U1.15, U4.1
SPI1_MOSI: J3.3, U1.14, U4.14
SPI1_SCK: J3.5, U1.13, U4.13
STATUS_LED: R43.1, U1.54
SWCLK: J1.3, U1.35
SWDIO: J1.2, U1.36
USB_DM: J2.6, U1.38
USB_DP: J2.5, U1.37
VBAT12: J6.1, J11.1, J14.1, J15.1, R7.1, R12.1, U7.1, U8.3, U9.3
VBAT_SENSE: R12.2, R13.1, U1.64
VIBE_SNS: J5.1, R6.1, U1.68
V_SOL: C30.1, C31.1, C32.1, D1.2, D2.2, D3.2, J7.1, J8.1, J9.1, R7.2, U7.2
XIN: C1.1, U1.33, X1.1
XOUT: C2.1, U1.34, X1.3

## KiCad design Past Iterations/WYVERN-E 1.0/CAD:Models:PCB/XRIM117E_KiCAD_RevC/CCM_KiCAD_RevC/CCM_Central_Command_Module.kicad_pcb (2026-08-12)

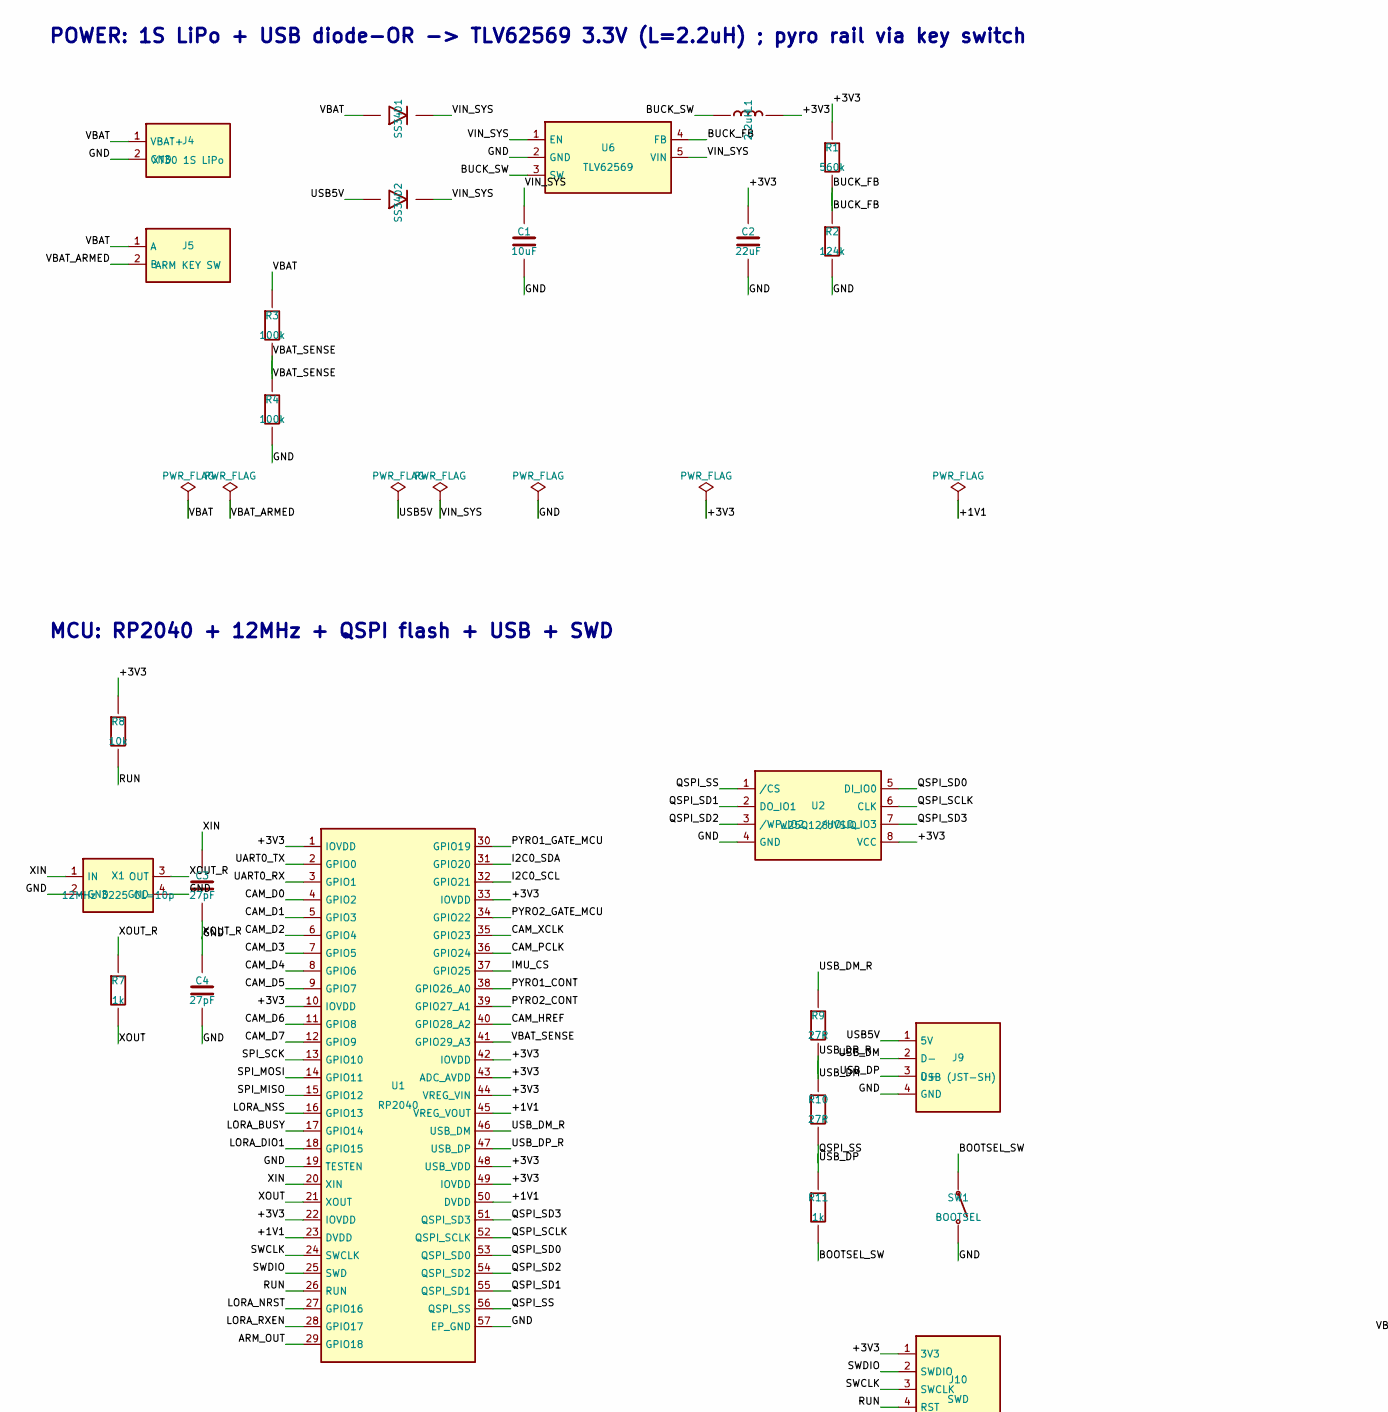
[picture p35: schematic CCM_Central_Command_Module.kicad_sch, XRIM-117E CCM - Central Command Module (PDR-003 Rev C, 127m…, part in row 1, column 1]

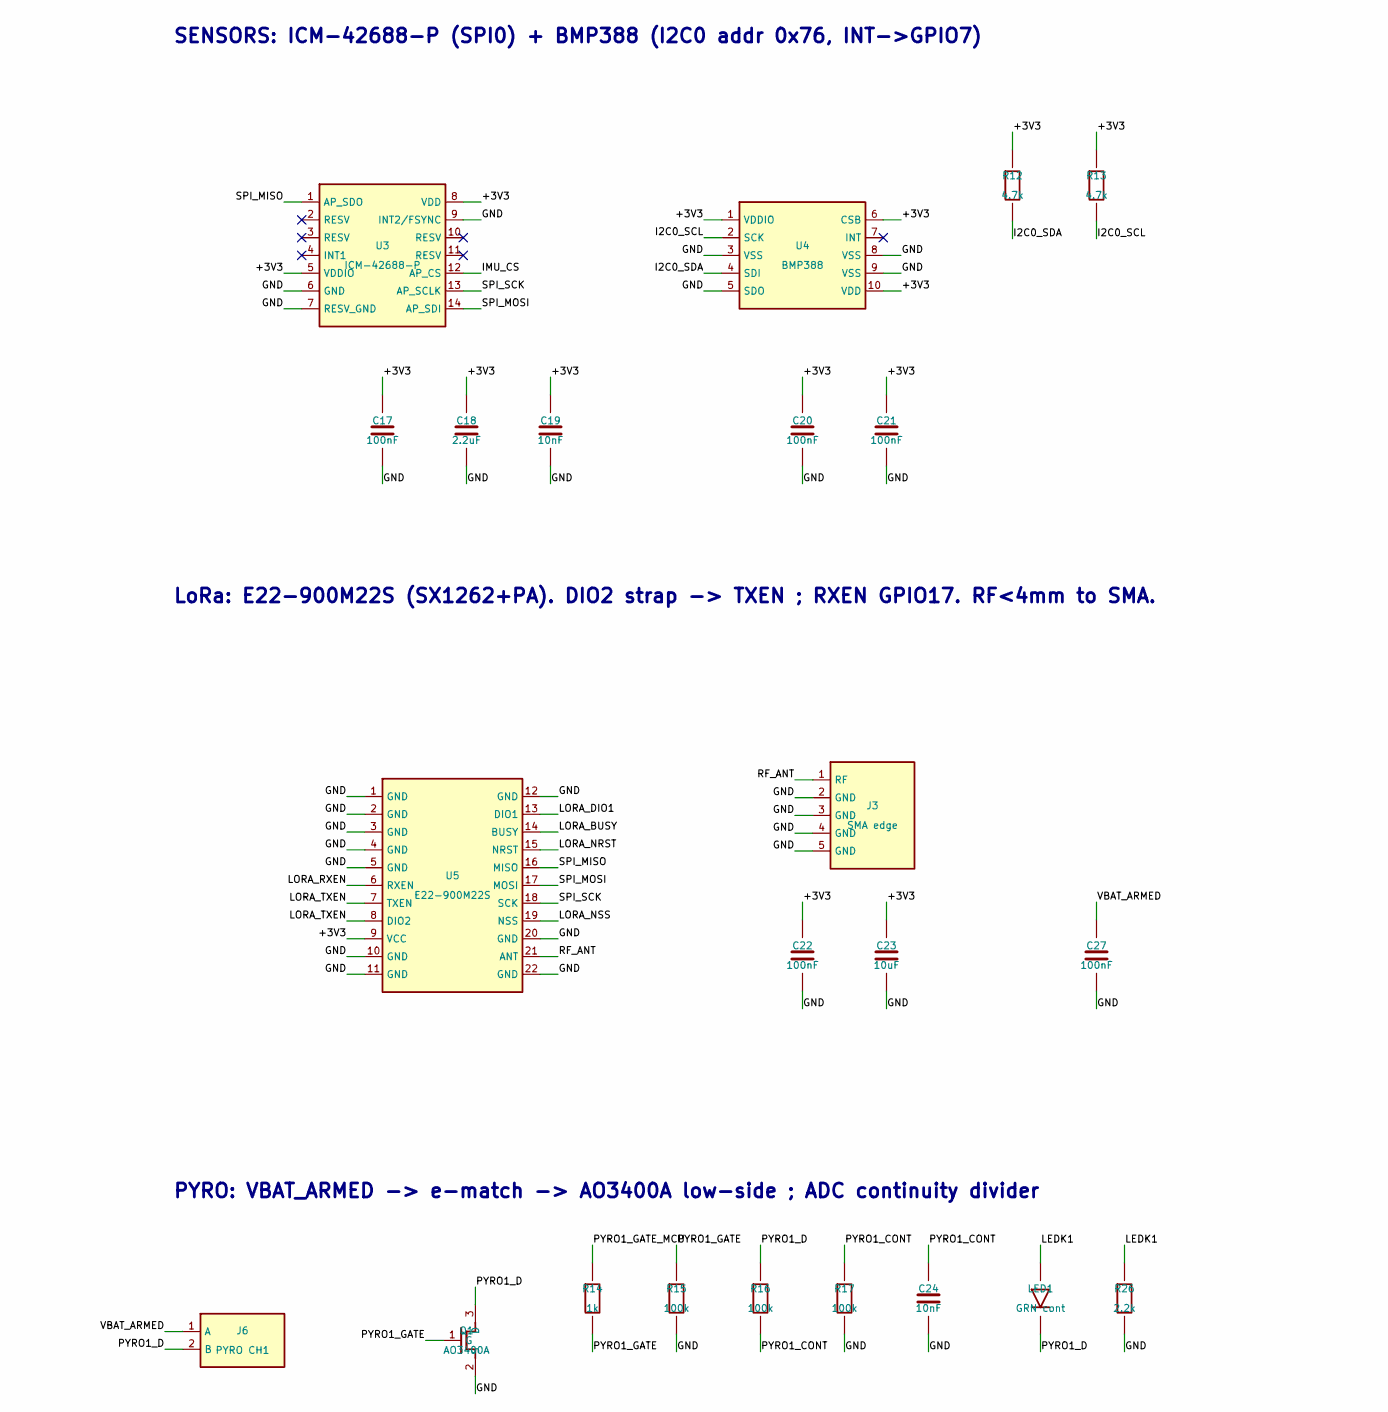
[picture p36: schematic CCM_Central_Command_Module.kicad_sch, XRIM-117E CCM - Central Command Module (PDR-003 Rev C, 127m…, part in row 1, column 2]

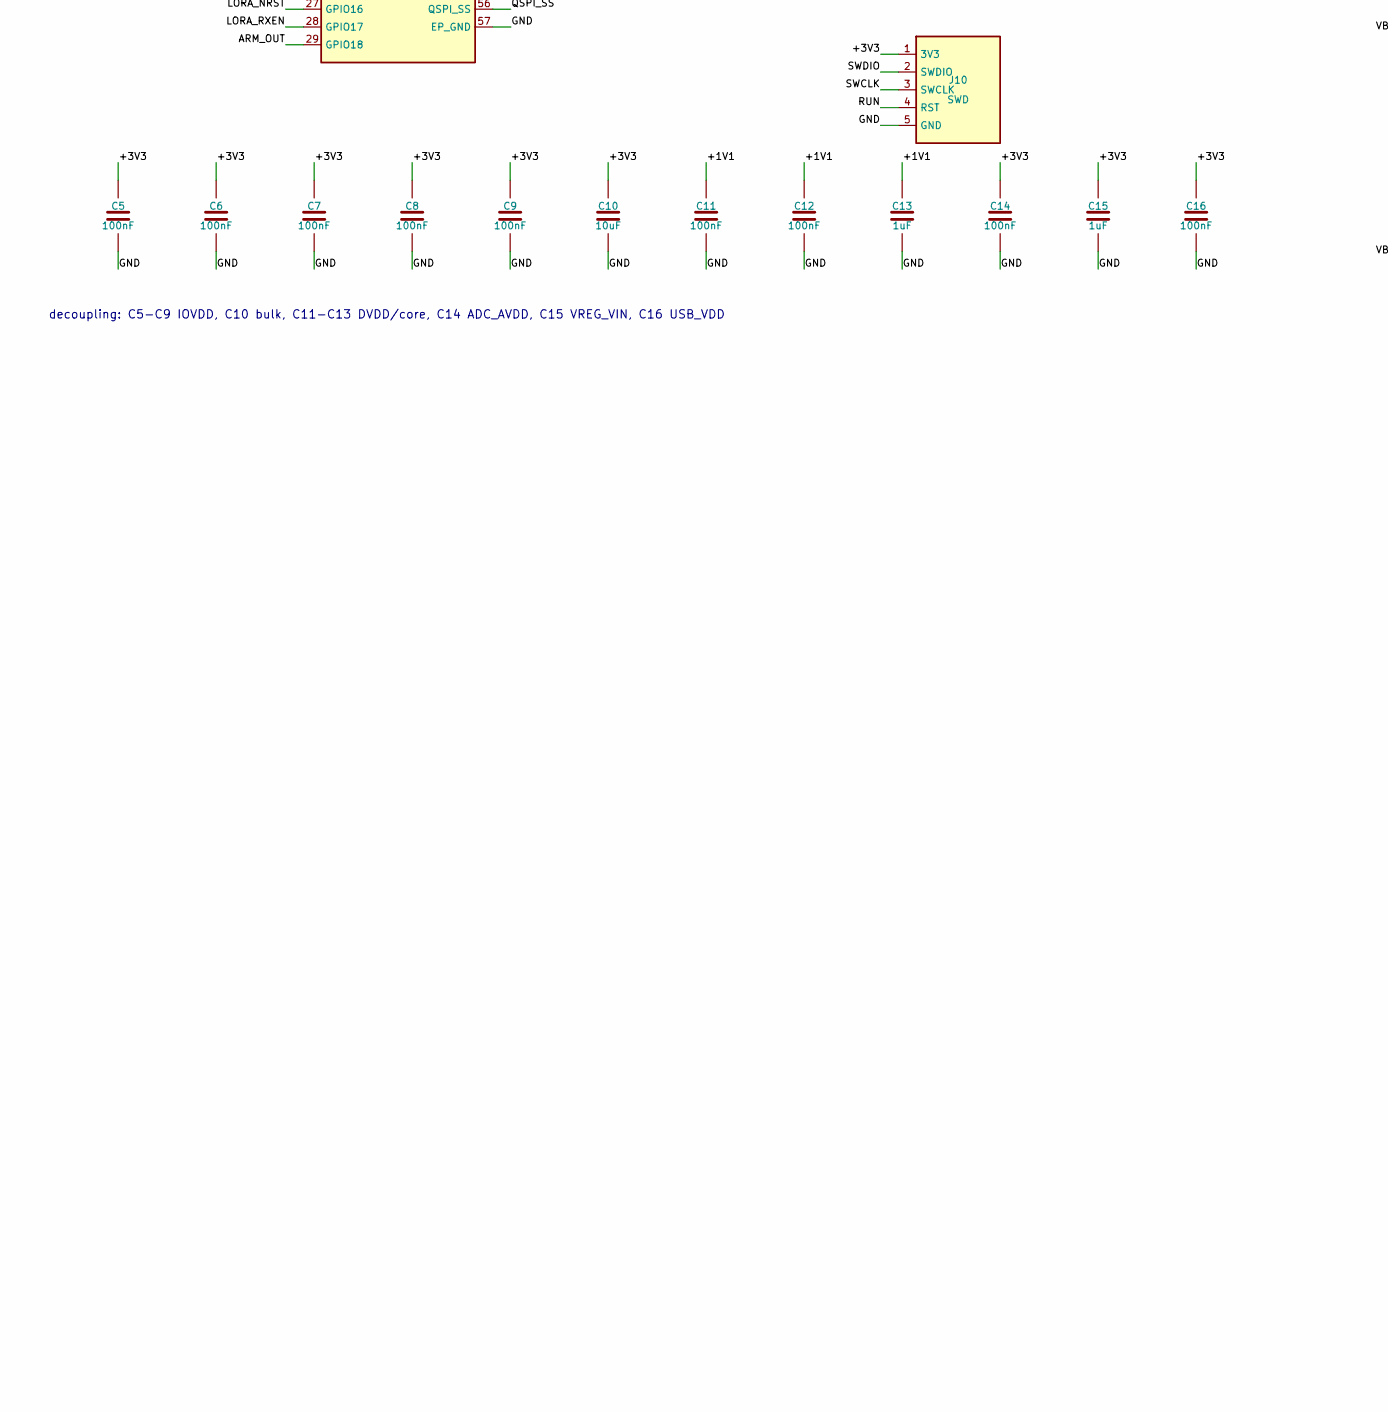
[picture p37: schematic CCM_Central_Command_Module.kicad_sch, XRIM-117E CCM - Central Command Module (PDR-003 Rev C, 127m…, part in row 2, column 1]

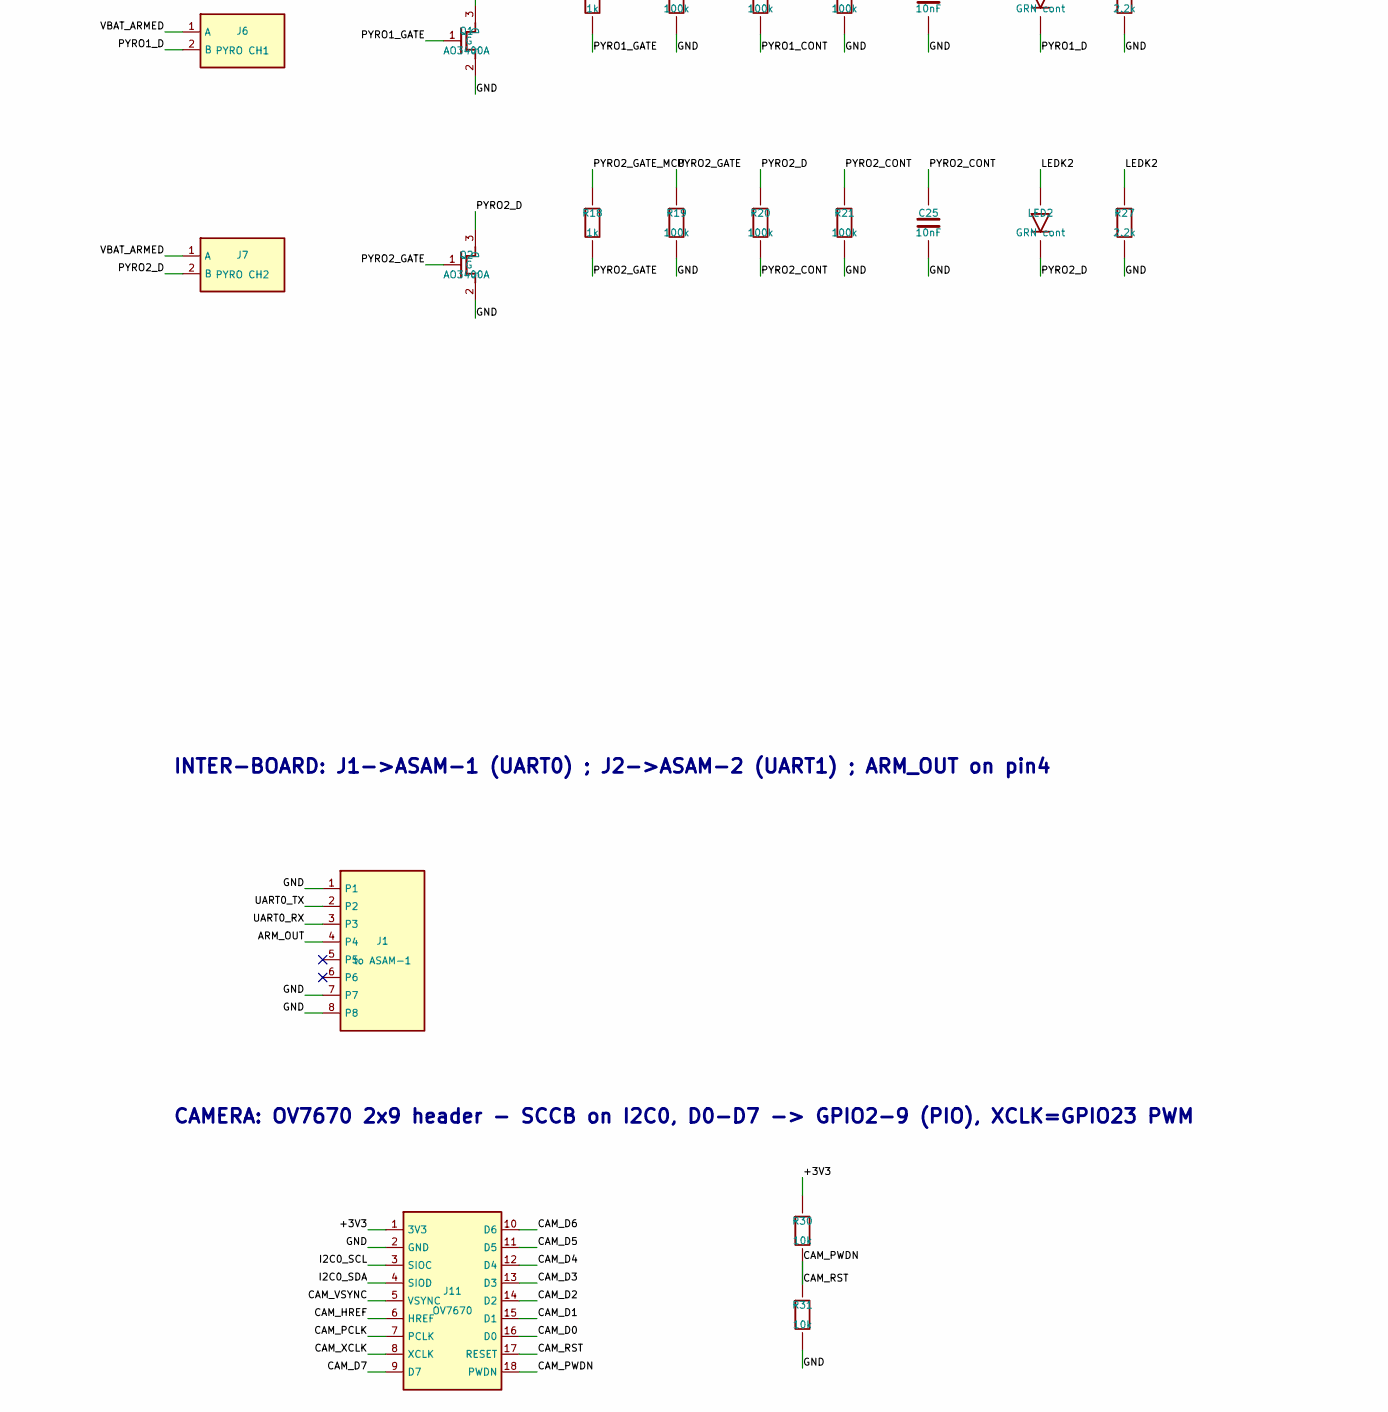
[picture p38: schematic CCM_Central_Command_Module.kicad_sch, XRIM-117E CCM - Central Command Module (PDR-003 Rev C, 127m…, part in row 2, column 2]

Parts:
C1, C10, C23: 10uF
C2: 22uF
C3, C4: 27pF
C5, C6, C7, C8, C9, C11, C12, C14, C16, C17, C20, C21, C22, C27: 100nF
C13, C15: 1uF
C18: 2.2uF
C19, C24, C25: 10nF
D1, D2: SS34; D_SMA
J1: to ASAM-1
J3: SMA edge
J4: XT30 1S LiPo
J5: ARM KEY SW
J6: PYRO CH1
J7: PYRO CH2
J9: USB (JST-SH)
J10: SWD
J11: OV7670
L1: 2.2uH; L_4x4mm
LED1, LED2: GRN cont
Q1, Q2: AO3400A
R1: 560k
R2: 124k
R3, R4, R15, R16, R17, R19, R20, R21: 100k
R7, R11, R14, R18: 1k
R8, R30, R31: 10k
R9, R10: 27R
R12, R13: 4.7k
R26, R27: 2.2k
SW1: BOOTSEL
U1: RP2040
U2: W25Q128JVSIQ
U3: ICM-42688-P
U4: BMP388
U5: E22-900M22S
U6: TLV62569
X1: 12MHz 3225 CL=10p

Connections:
+1V1: C11.1, C12.1, C13.1, U1.23 (DVDD), U1.45 (VREG_VOUT), U1.50 (DVDD)
+3V3: C2.1, C5.1, C6.1, C7.1, C8.1, C9.1, C10.1, C14.1, C15.1, C16.1, C17.1, C18.1, C19.1, C20.1, C21.1, C22.1, C23.1, J10.1 (3V3), J11.1 (3V3), L1.2, R1.1, R8.1, R12.1, R13.1, R30.1, U1.1 (IOVDD), U1.10 (IOVDD), U1.22 (IOVDD), U1.33 (IOVDD), U1.42 (IOVDD), U1.43 (ADC_AVDD), U1.44 (VREG_VIN), U1.48 (USB_VDD), U1.49 (IOVDD), U2.8 (VCC), U3.5 (VDDIO), U3.8 (VDD), U4.1 (VDDIO), U4.6 (CSB), U4.10 (VDD), U5.9 (VCC)
ARM_OUT: J1.4, U1.29 (GPIO18)
BOOTSEL_SW: R11.2, SW1.1
BUCK_FB: R1.2, R2.1, U6.4 (FB)
BUCK_SW: L1.1, U6.3 (SW)
CAM_D0: J11.16 (D0), U1.4 (GPIO2)
CAM_D1: J11.15 (D1), U1.5 (GPIO3)
CAM_D2: J11.14 (D2), U1.6 (GPIO4)
CAM_D3: J11.13 (D3), U1.7 (GPIO5)
CAM_D4: J11.12 (D4), U1.8 (GPIO6)
CAM_D5: J11.11 (D5), U1.9 (GPIO7)
CAM_D6: J11.10 (D6), U1.11 (GPIO8)
CAM_D7: J11.9 (D7), U1.12 (GPIO9)
CAM_HREF: J11.6 (HREF), U1.40 (GPIO28_A2)
CAM_PCLK: J11.7 (PCLK), U1.36 (GPIO24)
CAM_PWDN: J11.18 (PWDN), R31.1
CAM_RST: J11.17 (RESET), R30.2
CAM_VSYNC: J11.5 (VSYNC)
CAM_XCLK: J11.8 (XCLK), U1.35 (GPIO23)
I2C0_SCL: J11.3 (SIOC), R13.2, U1.32 (GPIO21), U4.2 (SCK)
I2C0_SDA: J11.4 (SIOD), R12.2, U1.31 (GPIO20), U4.4 (SDI)
IMU_CS: U1.37 (GPIO25), U3.12 (AP_CS)
LEDK1: LED1.1, R26.1
LEDK2: LED2.1, R27.1
LORA_BUSY: U1.17 (GPIO14), U5.14 (BUSY)
LORA_DIO1: U1.18 (GPIO15), U5.13 (DIO1)
LORA_NRST: U1.27 (GPIO16), U5.15 (NRST)
LORA_NSS: U1.16 (GPIO13), U5.19 (NSS)
LORA_RXEN: U1.28 (GPIO17), U5.6 (RXEN)
LORA_TXEN: U5.7 (TXEN), U5.8 (DIO2)
PYRO1_CONT: C24.1, R16.2, R17.1, U1.38 (GPIO26_A0)
PYRO1_D: J6.2 (B), LED1.2, Q1.3 (D), R16.1
PYRO1_GATE: Q1.1 (G), R14.2, R15.1
PYRO1_GATE_MCU: R14.1, U1.30 (GPIO19)
PYRO2_CONT: C25.1, R20.2, R21.1, U1.39 (GPIO27_A1)
PYRO2_D: J7.2 (B), LED2.2, Q2.3 (D), R20.1
PYRO2_GATE: Q2.1 (G), R18.2, R19.1
PYRO2_GATE_MCU: R18.1, U1.34 (GPIO22)
QSPI_SCLK: U1.52 (QSPI_SCLK), U2.6 (CLK)
QSPI_SD0: U1.53 (QSPI_SD0), U2.5 (DI_IO0)
QSPI_SD1: U1.55 (QSPI_SD1), U2.2 (DO_IO1)
QSPI_SD2: U1.54 (QSPI_SD2), U2.3 (/WP_IO2)
QSPI_SD3: U1.51 (QSPI_SD3), U2.7 (/HOLD_IO3)
RF_ANT: J3.1 (RF), U5.21 (ANT)
RUN: J10.4 (RST), R8.2, U1.26 (RUN)
SPI_MISO: U1.15 (GPIO12), U3.1 (AP_SDO), U5.16 (MISO)
SPI_MOSI: U1.14 (GPIO11), U3.14 (AP_SDI), U5.17 (MOSI)
SPI_SCK: U1.13 (GPIO10), U3.13 (AP_SCLK), U5.18 (SCK)
SWCLK: J10.3 (SWCLK), U1.24 (SWCLK)
SWDIO: J10.2 (SWDIO), U1.25 (SWD)
UART0_RX: J1.3, U1.3 (GPIO1)
UART0_TX: J1.2, U1.2 (GPIO0)
USB5V: D2.1, J9.1 (5V)
USB_DM: J9.2 (D-), R9.2
USB_DM_R: R9.1, U1.46 (USB_DM)
USB_DP_R: R10.1, U1.47 (USB_DP)
VBAT: D1.1, J4.1 (VBAT+), J5.1 (A), R3.1
VBAT_ARMED: C27.1, J5.2 (B), J6.1 (A), J7.1 (A)
VBAT_SENSE: R3.2, R4.1, U1.41 (GPIO29_A3)
VIN_SYS: C1.1, D1.2, D2.2, U6.1 (EN), U6.5 (VIN)
XIN: C3.1, U1.20 (XIN), X1.1 (IN)
XOUT: R7.2, U1.21 (XOUT)

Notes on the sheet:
POWER: 1S LiPo + USB diode-OR -> TLV62569 3.3V (L=2.2uH) ; pyro rail via key switch
MCU: RP2040 + 12MHz + QSPI flash + USB + SWD
decoupling: C5-C9 IOVDD, C10 bulk, C11-C13 DVDD/core, C14 ADC_AVDD, C15 VREG_VIN, C16 USB_VDD
SENSORS: ICM-42688-P (SPI0) + BMP388 (I2C0 addr 0x76, INT->GPIO7)
LoRa: E22-900M22S (SX1262+PA). DIO2 strap -> TXEN ; RXEN GPIO17. RF<4mm to SMA.
PYRO: VBAT_ARMED -> e-match -> AO3400A low-side ; ADC continuity divider
INTER-BOARD: J1->ASAM-1 (UART0) ; J2->ASAM-2 (UART1) ; ARM_OUT on pin4
CAMERA: OV7670 2x9 header - SCCB on I2C0, D0-D7 -> GPIO2-9 (PIO), XCLK=GPIO23 PWM

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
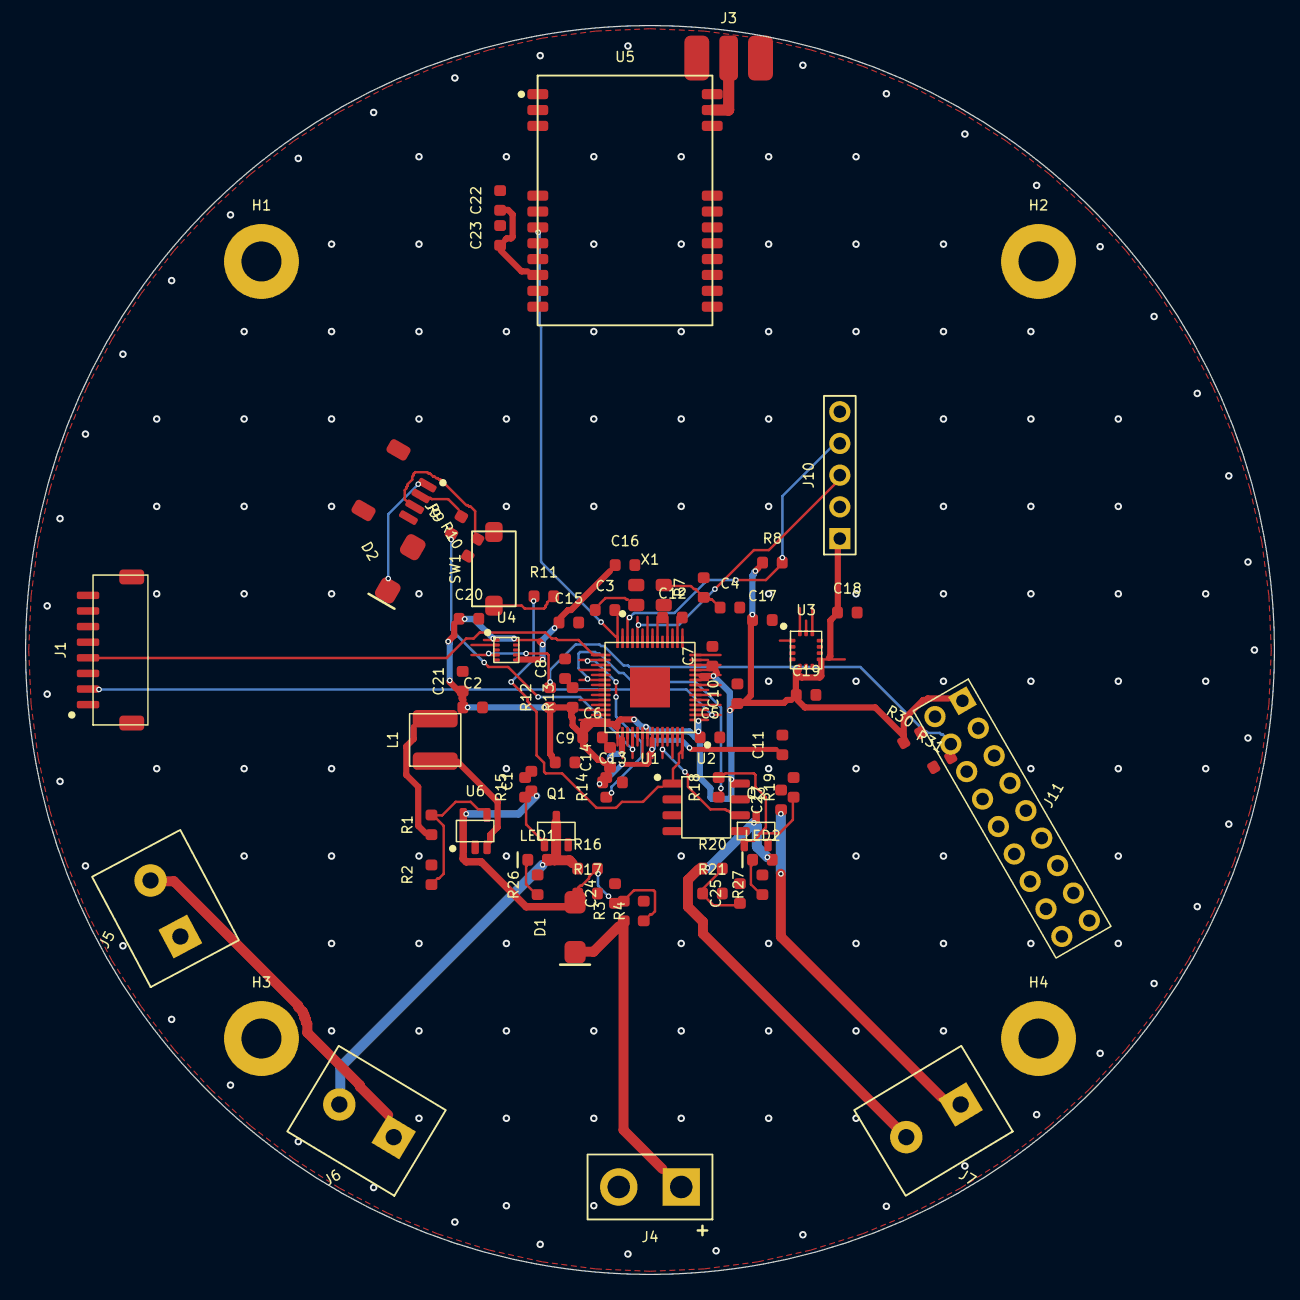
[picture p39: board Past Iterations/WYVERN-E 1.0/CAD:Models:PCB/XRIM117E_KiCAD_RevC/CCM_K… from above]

Board: 2 copper layers, 100.0 x 100.0 mm, 77 parts (0 on the bottom side), 66 nets.

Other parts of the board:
H1, H2, H3, H4: M3; MountingHole_M3

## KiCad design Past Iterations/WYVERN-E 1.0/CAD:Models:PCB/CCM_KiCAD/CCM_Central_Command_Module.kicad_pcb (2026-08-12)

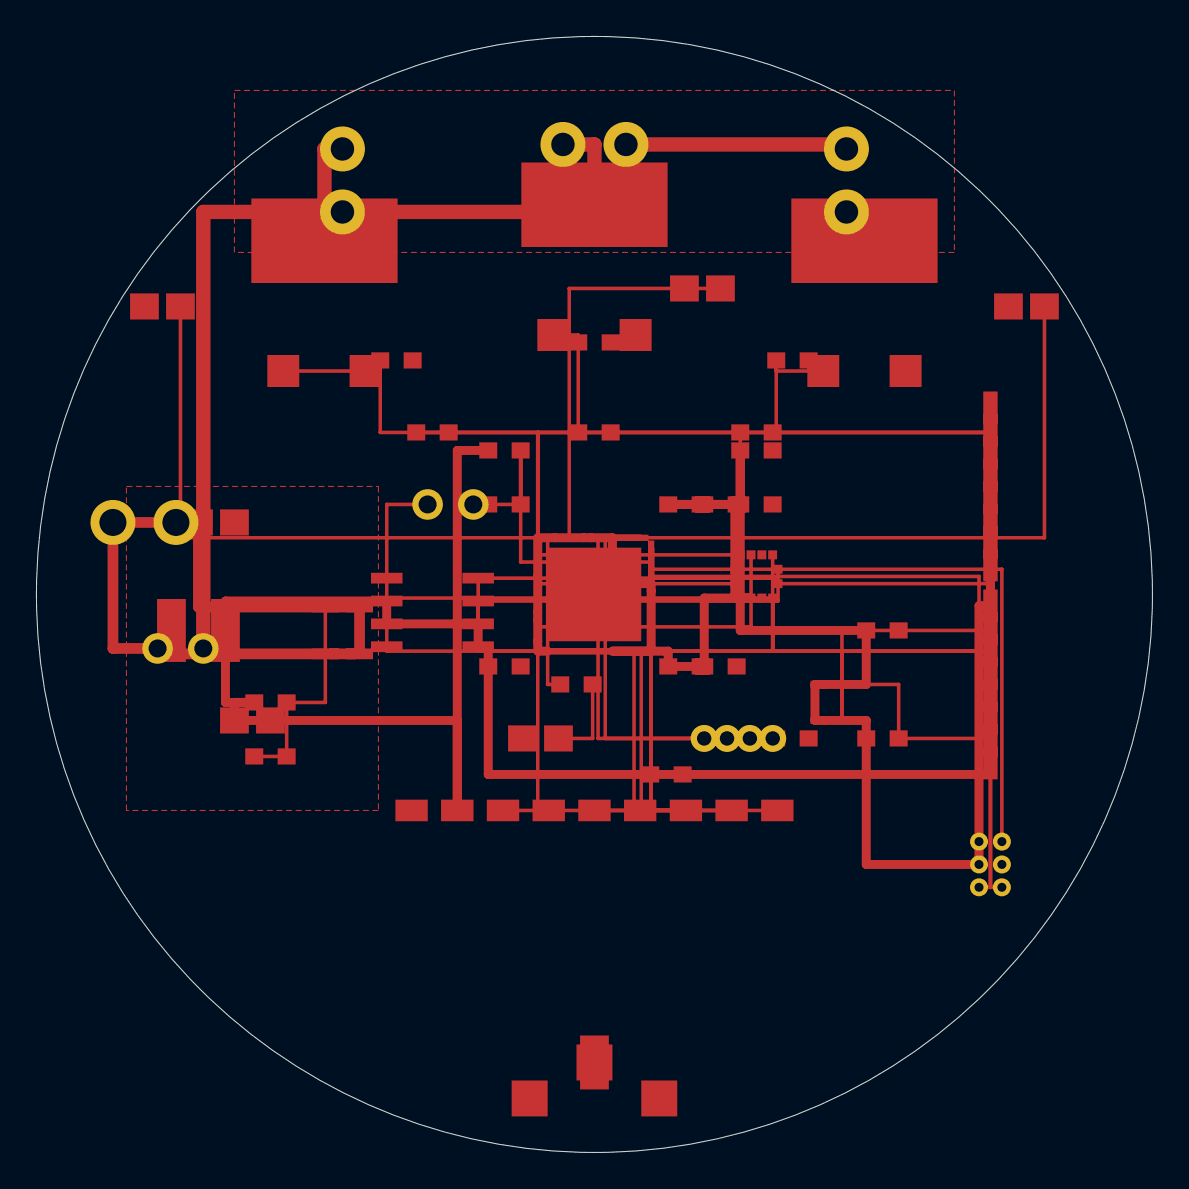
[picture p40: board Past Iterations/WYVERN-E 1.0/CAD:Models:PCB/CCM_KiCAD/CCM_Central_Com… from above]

Board: 2 copper layers, 62.0 x 62.0 mm, 49 parts (0 on the bottom side), 45 nets.

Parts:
C1: 47uF 10V; C_0805_2012Metric
C2: 22uF 6.3V; C_0805_2012Metric
C10, C12, C13, C14, C15, C20, C21, C30, C31: 100nF; C_0402_1005Metric
C11: 10uF; C_0402_1005Metric
J1, J2: JST-GH-8; JST_GH_SM08B-GHS-TB_1x08-1MP_P1.25mm_Horizontal
J3: SMA_Edge; SMA_Molex_0732511150_Horizontal
J4: XT30-M; PinHeader_1x02_P2.54mm_Vertical
J5: SW_2pin; PinHeader_1x02_P2.54mm_Vertical
J6, J7, J8: Screw_2; TerminalBlock_bornier-2_P3.5mm
J9: USB_TP; PinHeader_1x04_P1.27mm_Vertical
L1: 2.2uH; L_1210_3225Metric
LED1, LED2, LED3: Cont LED; LED_0805_2012Metric
LED4: Status; LED_0805_2012Metric
Q1, Q2, Q3: IRFZ44N; TO-263-3_TabEP
R1, R23, R24, R25: 10k; R_0402_1005Metric
R10, R11: 4.7k; R_0402_1005Metric
R20, R21, R22: 100R; R_0402_1005Metric
R26: 453k; R_0402_1005Metric
R27: 100k; R_0402_1005Metric
R28: 330R; R_0402_1005Metric
SW1: TC2030-SWD; TC2030-IDC-FP_2x03_P1.27mm_Vertical
SW_BOOT: SW_2pin; PinHeader_1x02_P2.54mm_Vertical
U1: RP2040; QFN-56-1EP_7x7mm_P0.4mm
U2: W25Q128; SOIC-8_3.9x4.9mm_P1.27mm
U3: ICM-42688-P; InvenSense_ICM-42688-P_LGA-14
U4: BMP388; Bosch_LGA-8_2x2.5mm
U5: E22-900M22S; Ebyte_E22-900M22S
U6: TLV62569; SOT-23-5

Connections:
+3V3: C2.1, C10.1, C11.1, C13.1, C14.1, C15.1, C20.1, C21.1, C30.1, J1.1, J2.1, L1.2, R1.1, R10.1, R11.1, R26.1, SW1.3, U1.1, U1.10, U1.22, U1.23, U1.33, U1.36, U1.37, U1.41, U1.47, U1.52, U1.53, U1.56, U2.3, U2.7, U2.8, U3.1, U3.2, U3.12, U4.1, U4.2, U4.7, U5.8
BUCK_SW: L1.1, U6.1
FB_3V3: R26.2, R27.1, U6.5
FLASH_CS: SW_BOOT.1, U1.8, U2.1
GND: C1.2, C2.2, C10.2, C11.2, C12.2, C13.2, C14.2, C15.2, C20.2, C21.2, C30.2, C31.2, J1.2, J2.2, J3.2, J3.3, J4.2, J9.1, LED1.K, LED2.K, LED3.K, LED4.K, Q1.2, Q2.2, Q3.2, R23.2, R24.2, R25.2, R27.2, SW1.4, SW_BOOT.2, U1.9, U1.19, U1.20, U1.21, U1.27, U1.28, U1.29, U1.30, U1.31, U1.32, U1.43, U1.49, U1.50, U1.55, U1.EP, U2.4, U3.3, U3.8, U3.11, U4.3, U4.6, U4.8, U5.9, U6.2
I2C0_SCL: J1.6, J2.6, R11.2, U1.12, U4.4
I2C0_SDA: J1.5, J2.5, R10.2, U1.11, U4.5
IMU_CS: U1.7, U3.7
IMU_INT1: U1.54, U3.9
IMU_INT2: U1.48, U3.10
LED_MCU: R28.1, U1.42
LED_STATUS: LED4.A, R28.2
LORA_BUSY: U1.17, U5.5
LORA_CS: U1.16, U5.4
LORA_IRQ: U1.18, U5.6
LORA_MISO: U1.15, U5.3
LORA_MOSI: U1.14, U5.2
LORA_NRST: U1.51, U5.7
LORA_SCK: U1.13, U5.1
NRST: C12.1, R1.2, U1.26
PYRO1_CONT: LED1.A, U1.40
PYRO1_D: J6.2, Q1.EP
PYRO1_GATE: J1.8, Q1.1, R20.2, R23.1
PYRO1_MCU: R20.1, U1.46
PYRO2_CONT: LED2.A, U1.39
PYRO2_D: J7.2, Q2.EP
PYRO2_GATE: J2.8, Q2.1, R21.2, R24.1
PYRO2_MCU: R21.1, U1.45
PYRO3_CONT: LED3.A, U1.38
PYRO3_D: J8.2, Q3.EP
PYRO3_GATE: Q3.1, R22.2, R25.1
PYRO3_MCU: R22.1, U1.44
RF_ANT: J3.1, U5.10
SPI0_MISO: U1.6, U2.2, U3.4
SPI0_MOSI: U1.5, U2.5, U3.6
SPI0_SCK: J1.7, J2.7, U1.4, U2.6, U3.5
SWCLK: SW1.1, U1.24
SWDIO: SW1.2, U1.25
UART0_RX: J1.4, J2.4, SW1.6, U1.3
UART0_TX: J1.3, J2.3, SW1.5, U1.2
USB5V: C31.1, J9.4
USB_DM: J9.2, U1.34
USB_DP: J9.3, U1.35
VBAT: C1.1, J4.1, J5.1, U6.3, U6.4
VBAT_ARMED: J5.2, J6.1, J7.1, J8.1

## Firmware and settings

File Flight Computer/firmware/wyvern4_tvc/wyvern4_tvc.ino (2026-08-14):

// GTR70E WYVERN — custom RP2350 flight computer (the Pico 2 W perfboard) + real-time TVC controller.
// ===============================================================================================
// Toolchain: Arduino-Pico core (earlephilhower), board "Raspberry Pi Pico 2 W" (rpipico2w) -- the bare-
// silicon RP2350 target (48 GPIO, QFN-80, external QSPI flash), NOT any Pico/Pico-W module profile.
// This board (the Pico 2 W perfboard) carries a standalone RP2350 (U1), not a Pico 2 module,
// so board profiles built around a module (rpipico2w, rpipico2) assume the wrong GPIO count, the
// wrong ADC-capable pin range, and a WiFi radio chip that isn't populated here.
//
// Libraries (Library Manager): Adafruit_BNO08x (external IMU, SH2 protocol), Adafruit_BNO085
// (both IMUs are BNO085, same driver, different address -- see imu_grv.h), Adafruit_BME680,
// Adafruit_BMP3XX (optional, no BMP388 populated on this board rev, see baro.h), INA226 (RobTillaart,
// battery/power monitor), plus the Arduino-Pico built-ins Servo, Wire, SPI, SD. WiFi/WiFiUdp remain
// linked for wifi_telemetry.h's bench-only code path, but this board has NO onboard radio chip (no
// CYW43439 in the BOM) -- WIFI_ENABLED must stay 0 unless an external WiFi module is added later.
//
// Recovery is MOTOR ejection (F15-4), separating the two body tubes at a single bulkhead joint —
// NO CO2, NO pyro bay, NO RRC3. The FC does NOT actuate recovery; it only logs/observes
// (Documentation/WYVERN_E4_Recovery.md).
// Read ../CONFLICTS.md before flying: it documents the PID-gain and recovery-timing values this
// code depends on.
//
// ----------------------------------- DUAL-CORE OWNERSHIP MAP -----------------------------------
// RP2350's two M33 cores share all peripherals at the silicon level (I2C, SPI0, UART0, the single
// ADC, GPIO). Concurrent multi-step bus transactions (I2C, SPI, UART) from BOTH cores at once is a
// real hazard (interleaved register writes = corrupted transactions), so this firmware gives each
// *bus peripheral* exactly one owning core, and uses single-writer/single-reader volatile flags
// (never multi-byte structs without a snapshot) to cross the core boundary:
//
//   core 0 (setup/loop)   owns: the single shared I2C bus (Wire, GP0 SDA / GP1 SCL) -- bay BNO085,
//                          external BNO085 (STEMMA-QT, bulkhead-boundary mount), BME688, and the
//                          decimated baro reads all share this one bus by address, no mux/second bus
//                          exists on this board -- plus the 2 servo PWM outputs and LAUNCH_IRQ sense.
//                          Runs the 500 Hz TVC loop. NEVER calls anything that can block
//                          (no SD, no UART, no WiFi, no delay()).
//   core 1 (setup1/loop1) owns: SPI0 (microSD), WiFi/UDP (inert, no radio chip), and the digital
//                          housekeeping pins (CAM_EN, RBF sense, status LED/buzzer). Drains the
//                          inter-core FIFO log queue. (Recovery is motor-driven — no deploy GPIO.)
//                          May block for milliseconds (SD writes) without ever touching the 500 Hz
//                          loop on core 0.
//
//   NOTE on the INA226 battery monitor: it sits on the SAME shared I2C bus as the IMUs/baro (no
//   second bus exists on this board -- see imu_grv.h's file header). Per the one-owning-core rule
//   above, it is therefore polled from CORE 0 (decimated, like the baro reads), NOT from core 1
//   where the rest of the housekeeping lives -- the alternative (core 1 also touching Wire) would
//   put two bus masters on one I2C peripheral, exactly the hazard this ownership scheme exists to
//   prevent. Only the resulting g_batt_v/g_battery_low/g_battery_critical flags cross to core 1.
//
//   Cross-core flags (each has exactly ONE writer core, documented at the declaration):
//     g_state            : FlightState, single byte -- written by core 0, read by core 1
//     g_rbf_pulled       : bool          -- written by core 1 (RBF sense), read by core 0
//     g_selftest_pass    : bool          -- written by core 1 (aggregates both cores' results,
//                                            but only core 1 WRITES this combined flag), read core 0
//     g_imu_init_mask    : uint8_t       -- written by core 0, read by core 1 (for self-test print)
//     g_baro_init_ok     : bool          -- written by core 0, read by core 1
//     g_battery_low      : bool          -- written by core 0 (INA226 shares the I2C bus core 0
//                                            owns -- see the NOTE above), read by core 1
//     g_battery_critical : bool          -- written by core 0, read by core 1
//     g_launch_ms        : uint32_t      -- written by core 0 once at launch, read by core 1
//
// Single-byte/bool/uint32_t volatile flags with one writer are safe on RP2350 without a mutex
// (no partial-write tearing possible at that width); nothing wider crosses cores outside the
// LogFrame FIFO, which is purpose-built for cross-core transfer (see sd_logger.h).
// WIFI_ENABLED must be defined before wifi_telemetry.h is included: that header pulls in <WiFi.h>,
// which assumes a CYW43439 radio chip. the Pico 2 W perfboard has NO radio chip in its BOM (see wifi_telemetry.h's
// file header) -- keep this at 0 unless a future board rev or external WiFi module changes that.
#define WIFI_ENABLED 0

#include <Wire.h>
#include <SPI.h>
#include <SD.h>
#include <Servo.h>
#include <Adafruit_BNO08x.h>
#include <Adafruit_BNO085.h>
#include <math.h>
#include "pico/multicore.h"

#include "wyvern_pid.h"
#include "imu_grv.h"
#include "baro.h"
#include "battery.h"
#include "launch_status.h"
#include "sd_logger.h"
#if WIFI_ENABLED
#include "wifi_telemetry.h"
#endif

// ---------- pin map (custom RP2350 the Pico 2 W perfboard) — CONFIRMED by tracing every pin in the netlist against
// the labeled schematic pinout -- see imu_grv.h and launch_status.h file headers for the detail.
#define SDA0 0
#define SCL0 1             // ONE shared I2C bus -> bay BNO085, external BNO085 (STEMMA-QT), BME688,
                            // INA226, LIS3MDL -- no mux, no second bus (core 0 owned)
#define PIN_SERVO_P 2       // pitch servo, JST connector U8 (PWM)
#define PIN_SERVO_Y 3       // yaw servo, JST connector U9 (PWM)
// GP4/GP5 -> JST connectors U10/U11 exist on the board but their intended function is undetermined
// from the netlist trace (spare axes? gas-pressure sensor? unused). Left unassigned -- flag for
// bench/silkscreen confirmation before building anything against them.
//
// RBF: there is NO software-readable remove-before-flight pin on this board. U13 (the physical
// slide switch near the power path) was the obvious candidate, but it connects to NOTHING on
// U1 in the netlist -- both its terminals sit in the power domain (one on the ~5V buck rail, one on
// an address-strap-adjacent node), not on any GPIO. Arming safety on the Pico 2 W perfboard as fabricated is provided
// entirely by U13 being a literal power switch: the board simply isn't running until it's flipped.
// GP12 (H1 header pin13) is a genuinely free, otherwise-unused GPIO -- PIN_RBF below keeps the
// existing INPUT_PULLUP software gate wired to it so a bodge wire (H1 pin13 to GND, switched by
// whatever RBF hardware gets added) will work if Sky wants a real software-visible RBF later. As
// fabricated, nothing is soldered there: the pin floats HIGH, g_rbf_pulled always reads true, and
// this stage of the BOOT gate provides no actual protection until that bodge exists.
#define PIN_RBF 12          // H1 header pin13 -- free GPIO, NOT wired to any switch on this board rev
#define BNO085_ADDR 0x4A    // external IMU, STEMMA-QT default
#define BNO085_ADDR 0x4B    // onboard IMU, CONFIRMED via netlist (COM3/ADR pin tied to GND)
#define SERVO_NEUTRAL_DEG 90.0f

// ---------- WiFi bench telemetry — EDIT before bench use. WIFI_ENABLED itself is defined above the
// includes (this board has no radio chip; see the note there) -- do not redefine it here. ----------
static const char* WIFI_SSID = "CHANGE_ME";
static const char* WIFI_PASS = "CHANGE_ME";
static const char* WIFI_DEST_IP = "192.168.1.100";

// ---------- timing constants (frozen parameters, CONFLICTS.md section 5) ----------
static const float CONTROL_DT_S = 0.002f;          // 500 Hz
static const unsigned long CONTROL_DT_US = 2000UL;
static const float TVC_ENGAGE_DELAY_S = 0.5f;       // past the F15 ignition spike
static const float BURNOUT_S = 3.45f;
static const float MANEUVER_SETPOINT_DEG = 4.0f;    // 02_tvc_control_loop.mermaid: "4 deg maneuver"
static const float MANEUVER_START_S = 2.0f;         // "vertical (t<2s) then 4 deg maneuver"
// Recovery is MOTOR-DRIVEN: the F15-4's own ejection charge fires ~4 s after burnout (t~7.45 s) and
// separates the two body tubes at the bulkhead joint — the FC does NOT actuate anything. This
// backstop is only the state machine's cutover to RECOVER (for logging/camera), set at the
// expected ejection time.
static const float RECOVER_BACKSTOP_S = 7.45f;      // F15-4 ejection = burnout 3.45 + 4.0 s delay
                                                     // (was 7.5 -- the canonical value everywhere
                                                     //  else in the repo is 7.45; see CONFLICTS.md 5)
static const unsigned long LANDED_QUIET_MS = 3000;  // accel+baro quiescent this long -> LANDED

// ---------- flight state machine (01_flight_state_machine.mermaid) ----------
enum FlightState : uint8_t { BOOT, ARMED, BOOST, COAST, RECOVER, DESCENT, LANDED };
static const char* state_name(FlightState s) {
  switch (s) {
    case BOOT: return "BOOT"; case ARMED: return "ARMED"; case BOOST: return "BOOST";
    case COAST: return "COAST"; case RECOVER: return "RECOVER"; case DESCENT: return "DESCENT";
    case LANDED: return "LANDED"; default: return "?";
  }
}

// ---------- cross-core flags (single-writer each — see ownership map above) ----------
volatile FlightState g_state = BOOT;                 // writer: core 0
volatile bool g_rbf_pulled = false;                  // writer: core 1
volatile bool g_selftest_pass = false;               // writer: core 1
volatile uint8_t g_imu_init_mask = 0;                // writer: core 0
volatile bool g_baro_init_ok = false;                // writer: core 0
volatile bool g_battery_low = false;                 // writer: core 0 (shares core 0's I2C bus)
volatile bool g_battery_critical = false;             // writer: core 0 (shares core 0's I2C bus)
volatile uint32_t g_launch_ms = 0;                   // writer: core 0 (set once at launch)
volatile bool g_imu_vote_fault = false;               // writer: core 0
volatile uint32_t g_dropped_log_frames = 0;           // writer: core 0
volatile float g_batt_v = 0.0f;                       // writer: core 0 (BatteryMonitor shares core 0's
                                                       // I2C bus, decimated update in loop() -- see the
                                                       // dual-core ownership NOTE above), read by core 1
                                                       // for logging/heartbeat/WiFi; single float, no
                                                       // partial-word tearing risk on RP2350's 32-bit
                                                       // bus, same rationale as TelemSnapshot below)

// Bench-telemetry snapshot: written by core 0 every tick, read by core 1's WiFi broadcaster only.
// Floats here are NOT given single-writer/single-reader atomicity guarantees beyond "no partial-
// word tearing on RP2350's 32-bit bus" -- acceptable because this feeds a ~20 Hz BENCH-ONLY display
// (wifi_telemetry.h), never the control loop or the flight log (which use the FIFO/LogFrame path
// instead, see sd_logger.h). A torn read here is, worst case, one stale-looking bench readout.
struct TelemSnapshot {
  float pitch_deg = 0, yaw_deg = 0, defl_pitch_deg = 0, defl_yaw_deg = 0, baro_alt_m = 0;
};
volatile TelemSnapshot g_telem;   // writer: core 0

// =================================================================================================
// CORE 0 — 500 Hz real-time TVC control loop. Nothing here may block.
// =================================================================================================
TriImu g_imu(Wire, BNO085_ADDR, BNO085_ADDR);
BaroPair g_baro(Wire);
BatteryMonitor g_battery(Wire);   // shares core 0's I2C bus -- see the dual-core ownership NOTE above
LaunchDetect g_launch;
DualAxisPID g_pid(wyvern_pid_defaults::make_config());
Servo g_servo_pitch, g_servo_yaw;

unsigned long g_loop_next_us = 0;
unsigned long g_t0_ms = 0;        // BOOT timestamp, for relative "uptime" displays only
unsigned long g_prev_tick_us = 0;  // for loop_dt_us jitter diagnostic in the LogFrame (schema v2)
bool g_armed_servo_neutral_done = false;
int g_baro_decimate_count = 0;
static const int BARO_DECIMATE = 5;   // baro updated every 5th control tick (~100 Hz), see header
int g_batt_decimate_count = 0;
static const int BATT_DECIMATE = 25;  // battery updated every 25th tick (~20 Hz) -- plenty for a
                                       // low/critical voltage gate, keeps I2C bus time small
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
void loop() {
  unsigned long now_us = micros();
  if ((long)(now_us - g_loop_next_us) < 0) return;   // hold to 500 Hz without delay()/blocking
  float dt = CONTROL_DT_S;
  g_loop_next_us += CONTROL_DT_US;
  unsigned long now_ms = millis();

  // ---- sensors (core 0 owns I2C0 + I2C1 exclusively, see ownership map) ----
  g_imu.update(now_ms);
  g_imu_vote_fault = g_imu.vote_fault();
  if (++g_baro_decimate_count >= BARO_DECIMATE) { g_baro_decimate_count = 0; g_baro.update(); }
  if (++g_batt_decimate_count >= BATT_DECIMATE) {
    g_batt_decimate_count = 0;
    g_battery.update();
    g_battery_low = g_battery.low_battery();
    g_battery_critical = g_battery.critical();
    g_batt_v = g_battery.voltage();
  }

  Quat q_body = g_imu.voted_body_quat();
  Quat q_gimbal = g_imu.gimbal_quat();
  Deflection defl = compute_deflection(q_body, q_gimbal);

  // crude pitch/yaw Euler readout off the voted body quaternion, small-angle convention matching
  // t2_imu_grv_deflection.ino, used for setpoint tracking error (NOT for the deflection itself,
  // which already uses the quaternion-product form directly).
  float body_pitch_rad = 2.0f * q_body.y;
  float body_yaw_rad = 2.0f * q_body.z;

  // |a| in g from the body BNO085's SH2_ACCELEROMETER report (enabled in TriImu::begin(), see
  // imu_grv.h) — drives both launch-detect (ARMED->BOOST, |a|>3g sustained) and the landing
  // quiescence check (DESCENT->LANDED, ~1g at rest). Falls back to a resting 1g default if the
  // accel channel is stale/uninitialized, so a sensor dropout can't be misread as a 0g freefall.
  float accel_mag_g = g_imu.body_accel_mag_g(now_ms);

  bool rbf_pulled = g_rbf_pulled;
  bool batt_critical = g_battery_critical;

  // Loop-timing diagnostic: actual elapsed micros() since the previous tick. Nominally
  // CONTROL_DT_US every time; a value that creeps above that under load (I2C retries, etc.) is
  // exactly the kind of jitter the dual-core split is meant to prevent, and is now visible in the
  // log instead of only inferable from t_ms deltas post-flight.
  uint32_t loop_dt_us = (uint32_t)(now_us - g_prev_tick_us);
  g_prev_tick_us = now_us;

  // Diagnostic taps for the LogFrame -- populated inside BOOST's TVC branch below when the loop is
  // actually closing on a setpoint; otherwise left at 0 so the CSV shows exactly "no command being
  // computed this tick" rather than stale/misleading values from an earlier state.
  float setp_pitch_rad = 0.0f;
  float err_pitch_rad = 0.0f, err_yaw_rad = 0.0f;
  float pid_p_pitch = 0.0f, pid_i_pitch = 0.0f, pid_d_pitch = 0.0f;
  float pid_p_yaw = 0.0f, pid_i_yaw = 0.0f, pid_d_yaw = 0.0f;

  switch (g_state) {
    case BOOT: {
      bool ok = g_selftest_pass && rbf_pulled && !batt_critical;
      if (ok) {
        g_state = ARMED;
        g_pid.reset();
        g_armed_servo_neutral_done = false;
      }
      core0_set_servos_neutral();
      break;
    }
    case ARMED: {
      core0_set_servos_neutral();
      bool launched = g_launch.update(accel_mag_g, now_ms);
      if (launched) {
        g_launch_ms = now_ms;
        g_pid.bumpless_reset(0.0f, 0.0f);
        g_state = BOOST;
      }
      break;
    }
    case BOOST: {
      float t_flight = (now_ms - g_launch_ms) / 1000.0f;
      if (t_flight >= BURNOUT_S) {
        core0_set_servos_neutral();
        g_state = COAST;
        break;
      }
      if (t_flight < TVC_ENGAGE_DELAY_S) {
        core0_set_servos_neutral();   // past ignition spike gate not yet open — neutral gimbal
      } else {
        float setp_pitch_deg = (t_flight < MANEUVER_START_S) ? 0.0f : MANEUVER_SETPOINT_DEG;
        setp_pitch_rad = radians(setp_pitch_deg);
        err_pitch_rad = setp_pitch_rad - body_pitch_rad;
        err_yaw_rad = 0.0f - body_yaw_rad;   // no yaw maneuver commanded, per design flowchart
        float cmd_pitch, cmd_yaw;
        g_pid.update(err_pitch_rad, err_yaw_rad, dt, cmd_pitch, cmd_yaw);
        core0_apply_servo_commands(cmd_pitch, cmd_yaw);

        // Term breakdown for the LogFrame -- read AFTER update() so integral_state()/
        // derivative_state() reflect this tick's values, not the previous one. p_term(err) is
        // recomputed from the same err just passed to update(), so it's exactly what update()
        // itself used internally (not a stale/lagged reconstruction).
        pid_p_pitch = g_pid.pitch.p_term(err_pitch_rad);
        pid_i_pitch = g_pid.pitch.config().ki * g_pid.pitch.integral_state();
        pid_d_pitch = g_pid.pitch.config().kd * g_pid.pitch.derivative_state();
        pid_p_yaw = g_pid.yaw.p_term(err_yaw_rad);
        pid_i_yaw = g_pid.yaw.config().ki * g_pid.yaw.integral_state();
        pid_d_yaw = g_pid.yaw.config().kd * g_pid.yaw.derivative_state();
      }
      break;
    }
    case COAST: {
      // No thrust -> no TVC authority (TVC needs thrust reaction). Neutral gimbal and coast; the
      // motor's own F15-4 ejection charge (~t=7.45 s) separates the two body tubes at the bulkhead
      // joint and deploys the chute — the FC does not fire anything. State advances to RECOVER at
      // the backstop (~ejection time) for logging.
      core0_set_servos_neutral();
      float t_flight = (now_ms - g_launch_ms) / 1000.0f;
      bool over_backstop = t_flight >= RECOVER_BACKSTOP_S;
      if (over_backstop) g_state = RECOVER;
      break;
    }
    case RECOVER: {
      core0_set_servos_neutral();
      g_state = DESCENT;   // brief transitional state; DESCENT does the actual landing watch
      break;
    }
    case DESCENT: {
      core0_set_servos_neutral();
      // Landing = quiescent accelerometer + stable baro altitude for LANDED_QUIET_MS. Implemented
      // on core 1 (which also owns the housekeeping timers) via g_state being writable from core 0
      // only — so this check stays here, core 0, using a small local hold-timer.
      static unsigned long quiet_since_ms = 0;
      bool quiescent = fabsf(accel_mag_g - 1.0f) < 0.15f;  // resting at ~1g, no big swings
      if (quiescent) {
        if (quiet_since_ms == 0) quiet_since_ms = now_ms;
        if (now_ms - quiet_since_ms >= LANDED_QUIET_MS) g_state = LANDED;
      } else {
        quiet_since_ms = 0;
      }
      break;
    }
    case LANDED: {
      core0_set_servos_neutral();
      break;
    }
  }

  // ---- push one log frame per tick into the inter-core FIFO (never blocks; drops if full) ----
  // Schema v2: every quantity the control loop already holds this tick, not just the final
  // actuator command -- see the schema-v2 note at the top of sd_logger.h for the rationale.
  LogFrame f{};
  f.t_ms = now_ms;
  f.t_flight_s = (g_launch_ms == 0) ? NAN : (now_ms - g_launch_ms) / 1000.0f;
  f.loop_dt_us = loop_dt_us;

  f.state = (uint8_t)g_state;
  f.imu_fault = g_imu_vote_fault ? 1 : 0;
  f.rbf_pulled = rbf_pulled ? 1 : 0;
  f.batt_flags = (g_battery_low ? 0x01 : 0x00) | (batt_critical ? 0x02 : 0x00);

  f.qb_w = q_body.w; f.qb_x = q_body.x; f.qb_y = q_body.y; f.qb_z = q_body.z;
  f.qg_w = q_gimbal.w; f.qg_x = q_gimbal.x; f.qg_y = q_gimbal.y; f.qg_z = q_gimbal.z;
  f.vote_disagree_rad = g_imu.vote_disagreement_rad();

  f.body_pitch_rad = body_pitch_rad; f.body_yaw_rad = body_yaw_rad;
  f.defl_pitch_rad = defl.pitch_rad; f.defl_yaw_rad = defl.yaw_rad;

  f.setp_pitch_rad = setp_pitch_rad;
  f.err_pitch_rad = err_pitch_rad; f.err_yaw_rad = err_yaw_rad;

  f.pid_p_pitch = pid_p_pitch; f.pid_i_pitch = pid_i_pitch; f.pid_d_pitch = pid_d_pitch;
  f.pid_p_yaw = pid_p_yaw; f.pid_i_yaw = pid_i_yaw; f.pid_d_yaw = pid_d_yaw;

  f.cmd_pitch_rad = g_pid.pitch.last_output(); f.cmd_yaw_rad = g_pid.yaw.last_output();

  f.baro_alt_m = g_baro.altitude_agl_m(); f.baro_temp_c = g_baro.temperature_c();
  f.accel_mag_g = accel_mag_g;
  f.batt_v = g_batt_v;   // g_battery is polled right here on core 0 (decimated, see BATT_DECIMATE
                          // above) since it shares this core's I2C bus -- no cross-core read needed
                          // for this particular field, unlike most of the other g_* flags.
  f.dropped_frames_cum = g_dropped_log_frames;

  if (!log_push(f)) g_dropped_log_frames++;
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

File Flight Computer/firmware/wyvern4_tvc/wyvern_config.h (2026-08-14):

#pragma once
// ================================================================================================
// GTR70E WYVERN, build configuration for the Pico 2 W perfboard flight computer.
//
// One firmware image serves two roles. Flight uses both IMUs; the ground TVC/servo test stand
// reuses the identical electronics stack bolted to a bench, where the bay IMU measures nothing
// useful and its absence must not fail the self-test.
//
// Select the role by defining WYVERN_GROUND_TEST at build time (Arduino IDE: add
// `-DWYVERN_GROUND_TEST=1` to the build flags, or just flip the default below before flashing
// the bench unit).
//
// Hardware: Raspberry Pi Pico 2 W on a 20x24 (50x70 mm) perfboard. All four sensors are Adafruit
// STEMMA-QT breakouts landing on one shared I2C bus. See
// `Flight Computer/wiring/wyvern_perfboard_wiring.svg` for the hole-by-hole wiring.
// ================================================================================================

#ifndef WYVERN_GROUND_TEST
#define WYVERN_GROUND_TEST 0   // 0 = flight vehicle, 1 = ground TVC/servo test stand
#endif

// ---------------------------------------------------------------------------- I2C bus + addresses
// Both IMUs are BNO085 on the same bus, separated by the DI/address pin:
//   gimbal unit  -- DI unconnected (breakout default)      -> 0x4A
//   bay unit     -- DI wired to 3V3 on the perfboard        -> 0x4B
// Baros are separated by their SDO straps:
//   BME688       -- SDO wired to GND                        -> 0x76
//   BMP388       -- SDO unconnected (breakout default)       -> 0x77
#define WYV_PIN_SDA        0    // GP0, Pico physical pin 1
#define WYV_PIN_SCL        1    // GP1, Pico physical pin 2
#define WYV_I2C_HZ         400000UL

#define WYV_ADDR_IMU_GIMBAL 0x4A  // BNO085 on the TVC gimbal, via STEMMA-QT cable
#define WYV_ADDR_IMU_BAY    0x4B  // BNO085 in the electronics bay (flight only)
#define WYV_ADDR_BME688     0x76
#define WYV_ADDR_BMP388     0x77

// ---------------------------------------------------------------------------------- servo outputs
#define WYV_PIN_SERVO_PITCH 2   // GP2, Pico physical pin 4
#define WYV_PIN_SERVO_YAW   3   // GP3, Pico physical pin 5

// ------------------------------------------------------------------------------- microSD on SPI1
#define WYV_PIN_SD_MISO     8   // GP8,  physical 11
#define WYV_PIN_SD_CS       9   // GP9,  physical 12
#define WYV_PIN_SD_SCK     10   // GP10, physical 14
#define WYV_PIN_SD_MOSI    11   // GP11, physical 15

// ------------------------------------------------------------------------------- battery monitor
// 100k / 47k divider from the armed pack rail to GP26 (ADC0), 100 nF to GND on the tap.
// Vadc = Vpack * 47/147 -> 2.686 V at 8.4 V full charge, 1.918 V at the 6.0 V cutoff.
#define WYV_PIN_VBAT_ADC   26
#define WYV_VBAT_DIV_TOP   100000.0f
#define WYV_VBAT_DIV_BOT    47000.0f
#define WYV_VBAT_RATIO     ((WYV_VBAT_DIV_TOP + WYV_VBAT_DIV_BOT) / WYV_VBAT_DIV_BOT) // 3.128
#define WYV_ADC_VREF       3.3f
#define WYV_VBAT_WARN_V    6.4f   // 2S, ~3.20 V/cell
#define WYV_VBAT_CRIT_V    6.0f   // 2S, ~3.00 V/cell

// ------------------------------------------------------------------------------------ role gating
#if WYVERN_GROUND_TEST
  // Bench stand: the board is bolted down, so the bay IMU is not populated and not required.
  // Attitude comes solely from the gimbal unit, which is what the stand is measuring.
  #define WYV_REQUIRE_BAY_IMU   0
  #define WYV_ENABLE_LAUNCH_DET 0   // no launch to detect on a bench
  #define WYV_ENABLE_RECOVERY   0   // no deployment logic
  #define WYV_ROLE_NAME         "GROUND-TVC-STAND"
#else
  #define WYV_REQUIRE_BAY_IMU   1
  #define WYV_ENABLE_LAUNCH_DET 1
  #define WYV_ENABLE_RECOVERY   1
  #define WYV_ROLE_NAME         "FLIGHT"
#endif

// ------------------------------------------------------------------------------ separation event
// The Upper BT and Lower BT part at the bulkhead when the F15-4 ejection charge fires. Everything
// in the TVC bay -- both servos and the gimbal BNO085 (0x4A) -- crosses that joint on dupont
// male-female extension leads, which simply pull apart. Only the aramid shock cord stays attached.
//
// So after DEPLOY_T the gimbal IMU dropping off the bus and the servos going dead are EXPECTED,
// not faults. Attitude for the descent comes from the bay unit (0x4B), which never crosses the
// joint. The I2C driver must have a real timeout, or a read to the now-absent 0x4A will block the
// control loop exactly when descent logging matters.
#define WYV_DEPLOY_T_MS       7450UL   // ejection: burnout 3.45 s + F15-4's 4 s delay
#define WYV_I2C_TIMEOUT_US    2000UL   // per-transaction ceiling; a missing device must NACK, not hang
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

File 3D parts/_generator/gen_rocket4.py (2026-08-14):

#!/usr/bin/env python3
"""GTR70E WYVERN, 70 mm single-stage FINNED TVC sustainer (F15-4, motor-ejection recovery via
two-body-tube separation at a single bulkhead joint, NO bypass tube) + 3-axis TVC balance
(servo test stand) + static thrust stand + static deflector.

Architecture (`Documentation/WYVERN_E4_Recovery.md`, `CONFLICTS.md` §6/§8,
`Documentation/WYVERN_E4_Mathematics.md`):

  Upper BT (ASA-Aero, foamed 0.65 g/cm3): nose + recovery wadding/FC bay (avionics housing,
            no motor heat, no ejection-gas load -- lightest zone in the stack). Houses the Pico 2 W
            perfboard as a 50 x 70 mm axial card in a pair of slotted carrier disks, plus the
            camera, LiPo and UBEC. Arming switch is reached by pulling the nose cone.
  Lower BT (ASA-Aero, foamed 0.65 g/cm3): chute+cord+wadding zone + TVC bay, ONE continuous
            tube. Hoop stress under the 140 kPa ejection pulse (`WYVERN_E4_FEA_Structural.md`
            §4.1 load): sigma = p*r/t = 2.93 MPa, SF ~10x vs solid-ASA yield (30 MPa), ~6x even
            under a conservative 60%-strength-retention assumption for the foamed variant --
            comfortable positive margin, same logic as the >>1 flight-load SF elsewhere in that
            doc. Fin bond and ejection-gas thermal exposure are unaffected by the tube material
            (fins are a separate PETG-CF part bonded to the tube's solid outer perimeter shell,
            and the bulkhead -- the actual direct-gas-exposure part per FEA_Structural.md §4.2 --
            is PETG-CF).
  TVC assembly (PC-FR, 1.20 g/cm3): motor mount + gimbal only. PC-FR is the LIGHTER of the two
            non-foamed materials here (1.20 vs PETG-CF's 1.30 g/cm3) and is picked for its
            thermal role next to the nozzle.
  Bulkhead joint (PETG-CF): the ONE bulkhead between Upper BT and Lower BT, a friction-fit/
            shear-pin RELEASE joint, NOT gas-sealed. Direct ejection-gas-exposure part per
            FEA_Structural.md §4.2.
  Fins (PETG-CF): 87 mm span, root 70 / tip 35 / LE-sweep 25 / thickness 3, all mm.

--------------------------------------------------------------------------------------------
DFM practices used throughout this file:
  - Every mating tube/disk/ring interface carries an explicit slip-fit or press-fit tolerance
    (FIT_SLIP / FIT_PRESS below), named, not accidental.
  - Every bolted joint uses an M3 heat-set-insert boss (pilot hole sized for the standard
    knurled brass insert) instead of a bare hole into raw plastic.
  - The gimbal's pivot points are through-holes sized for a real metal pivot pin/screw, so the
    joint can actually rotate once assembled.
  - Hardware interface dimensions (servo mounting flange, load-cell body/hole spacing, HX711
    board) are TYPICAL-CLASS figures for the specific purchased parts (EMAX ES08MA II, Adafruit
    5kg/1kg strain-gauge cells, Adafruit HX711), not measured off the actual bench hardware.
    Every such block is tagged VERIFY-WITH-CALIPERS in a comment; treat as "will assemble",
    confirm against the real part before the final print run, same epistemic standard the rest
    of this repo holds unverified numbers to (see CONFLICTS.md #9).
--------------------------------------------------------------------------------------------
"""
import os, json
import math
from wcad import (S, cyl, tube, cone, box, sphere, ogive_nose, fin, _revolve,
                   export_step, export_stl, hole_cutter, boss, insert_boss, bolt_circle)

def ellipsoid_nose(R, L, wall=None, z=0):
    n = 60; pts = [(max(R*math.sqrt(max(1-(L*i/n/L)**2, 0.0)), 0.0), L*i/n) for i in range(n+1)]
    return _revolve(pts, z, wall)

ROOT = os.path.abspath(os.path.join(os.path.dirname(__file__), "..", ".."))
DROCK = os.path.join(ROOT, "3D parts")
DSTAND = os.path.join(ROOT, "Motor Test Stand", "TVC Thrust-Vector Balance")
DSTATIC = os.path.join(ROOT, "Motor Test Stand", "Static Stand (thrust + deflector)")
for d in (DROCK, DSTAND, DSTATIC): os.makedirs(d, exist_ok=True)

# ================================================================================================
# GLOBAL DFM CONSTANTS -- named once, used everywhere. Change here, not per-part.
# ================================================================================================
FIT_SLIP = 0.20   # radial clearance for parts that slide together (tube-in-tube, disk-in-bore), mm
FIT_PRESS = -0.10  # radial interference for parts meant to friction-hold (ring onto motor tube), mm
WALL = 1.6         # airframe wall, all materials, FEA-verified ~340x min SF (FEA_Structural.md #1-2)

M3 = dict(PILOT=4.2, BOSS_OD=8.0, BOSS_H=6.0, CLR=3.4, HEAD_CB_D=6.4, HEAD_CB_H=3.2)
# ^ M3 heat-set brass insert (standard 4.0-4.2mm pilot per typical knurled-insert vendor specs),
#   M3_CLR is a clearance-fit through-hole for a bare M3 bolt shank, HEAD_CB is a socket-cap
#   counterbore. These are catalog-standard, not part-specific -- safe to trust as-is.

# TYPICAL-CLASS, VERIFY-WITH-CALIPERS before the final print (see module docstring):
SERVO = dict(SPAN=28.0, PITCH=10.0, HOLE_D=2.2, BODY_W=12.4, BODY_L=23.0, BODY_H=29.4)
# EMAX ES08MA II metal-gear micro servo (BOM), standard "micro/9g-class" mounting flange:
# SPAN = tab-to-tab hole center distance, PITCH = front/back hole spacing on one tab.
LC5 = dict(W=12.7, L=76.0, MT_HOLE_D=5.5, MT_PITCH=10.0, SENSE_HOLE_D=5.5)
# Adafruit 5kg straight-bar strain-gauge load cell (TAL221-class), fixed (mounting) end 2 holes,
# free (sensing) end 1 hole.
LC1 = dict(W=12.7, L=55.0, MT_HOLE_D=4.2, MT_PITCH=8.0, SENSE_HOLE_D=4.2)
# Adafruit 1kg strain-gauge load cell, same family, shorter body.
HX711 = dict(W=20.5, L=27.0, HOLE_D=2.7, HOLE_INSET=2.5)
# Adafruit HX711 24-bit ADC breakout, 2 diagonal mounting holes near the board corners.
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

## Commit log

2026-08-10 PCB + BOM update!
    [Autorouter_PCB1_2026-8-9.dsn, BOM_Board1_PCB1_2026-08-09.xlsx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]
2026-08-10 CAD updates
    [STEM+Tunnel+Promo+-+0.4n.3mf, WYVERN_E4_BOM.xlsx, WYVERN_E4_BOM_Active.xlsx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]
2026-08-12 Update - but the PCB no work :(
    [WYVERN_E4_BOM.xlsx, WYVERN_E4_BOM_Active.xlsx, WYVERN_E4_flight_harness.kicad_sch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]
2026-08-12 Update! PCB and old stuff!
    [.kicad_sch, 00_full_assembly.step, 00_full_assembly.stl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]
2026-08-13 Update ig... PCB still doesnt work :(
    [WYVERN_E4_flight_harness.kicad_sch]
2026-08-14 Update - No more PCB
    [00_full_assembly.step, 00_full_assembly.stl, 01_nose_cone_ellipsoid_ASAAero.step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]
